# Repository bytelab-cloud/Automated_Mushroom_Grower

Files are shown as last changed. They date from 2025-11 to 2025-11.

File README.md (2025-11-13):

# Automated Mushroom Grower

Below is a list of components that are required for the project along with advice for assembling everything.

Youtube Video - https://youtu.be/puENLGAer3o

<h2>Components</h2>

<h3>Main</h3>

 - Switches - https://amzn.to/43ZM5kb

 - 2.1mm x 5.5mm Barrel Plug (Power) - https://amzn.to/488htiZ

 - Buck Converter 3.0-40V to 1.5-35V - https://amzn.to/49MK26M

 - Humidifier Module - https://amzn.to/47Rz90S

 - 24V Relay Module - https://amzn.to/4paiQUi

 - Arduino Uno - https://amzn.to/47DPRCc

 - Prototype PCB Board - https://amzn.to/3JXiYaw

 - 1.8" SPI LCD Display Module - https://amzn.to/4nQIpbJ

 - 1 Inch Diameter tube - https://amzn.to/4hRGUIU

 - 12v LED Strip - https://amzn.to/443jgU0

 - 12v Power Supply - https://amzn.to/4paiY6e

 - 60mm Fan - https://amzn.to/3JTiFO1

 - SHT 31 sensor - https://amzn.to/48c7MQA

   - I havent tested it but the code should also work with a cheaper SHT 30 sensor you just sacrifice some accuracy in readings

 - Resistors

 - Transistors

 - 100uf Capacitors

 - Wire / Jumper Wires

<h3>Optional</h3>

 - Pin Headers (For easier connection of jumpoer wires to pcb board)

 - Heat Set Inserts (I did not use them but it could make it easier)

 - Heat Shrink

<h2>Assembly</h2>

<h3>3D Printed Parts</h3>

Almost all of the 3D printed parts can just be screwed together except for the top part of the humidifier and the top of the case for the electronics. The case is designed this way so there isnt a need for a lot of supports when printing the case.

 - For the case for the electronics the top can welded together using acetone or glue the rest of assembly for the case just requires screws and is simple and straight foward to assemble.

 - The humidifier is made up of 3 different parts that require some form of welding or gluing.

     - For connecting the top plate of the humidifier to the bottom exhaust port you can use acetone to weld the parts together and use hot glue to create a seal around the edges.
  
     - For connecting the bottom exhaust to the top exhaust you can do the same acetone welding process to connect the 2 parts but to make sure it is sealed it is preferred to use silicone but hot glue works too.

 <h3>Electronics</h3>

 Most of the electronics are stright foward except for the screen which I have forund to work better when the LED power pin is connected the arduino rather then drawing 5v from the pcb.

  - <h3>Transistors (Humidifier Module and LED Strip)</h3>
  
    - 2 transistors are used in the machine 1 controls the humidifier module which is connected to pin 6 on the arduino along with the LED strip which gets connected to pin 3 on the arduino.
   
    - The humidifier module requires a simple modification for proper fuction you simply need to remove the push button on the module board so that when the board receives power it turns on automatically.

 - <h3>Relay (Fan)</h3>

    - The relay connects to the fan and requires 12v and is connected to pin 7 on the arduino

- <h3>Buck Converter</h3>

  - Depending on your power supply you with either need 1 or 2 buck converters if your using a 12v power supply you need to split it into 2 channels 1 that will directly connect to the pcb to powwer the 12v fan and LED strip and 1 channel that is stepped down to 5v in the buck converter that then connects to the pcb to power the rest of the electronics. If you are using a higher voltage power supply youll need 2 buck converters 1 that steps down to 12v and one that steps down to 5v both are connected the same way after passing through the buck converter.

- <h3>Switch</h3>

  - the switch gets connecteed to pin 12 on the arduino and ground.

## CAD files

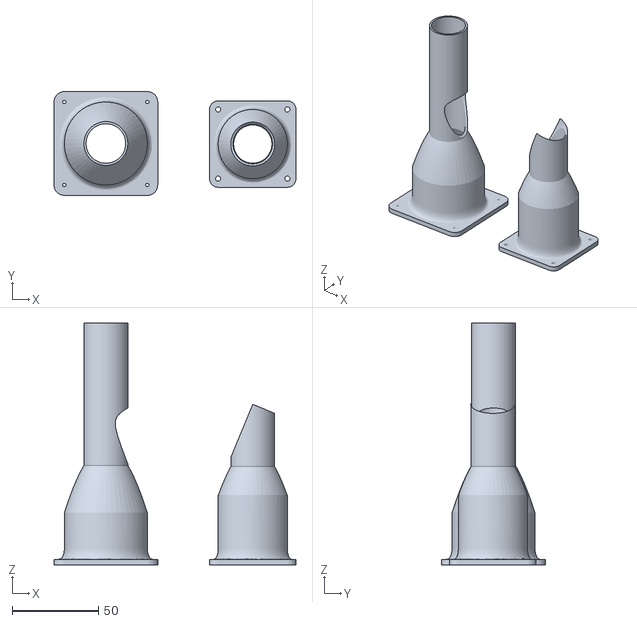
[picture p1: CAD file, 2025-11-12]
humidifier_exhaust.stl
139.9 x 60.0 x 139.7

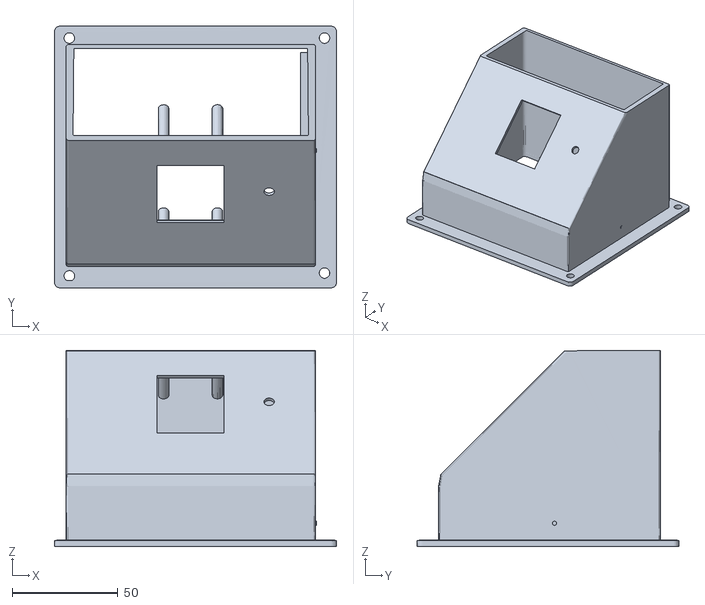
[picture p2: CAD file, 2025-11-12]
case.stl
133.3 x 123.8 x 92.7

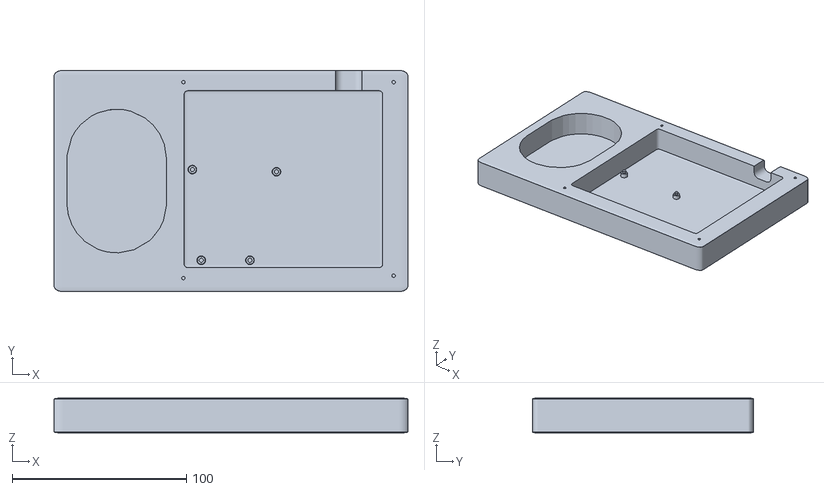
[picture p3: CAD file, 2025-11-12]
base_plate.stl
203.2 x 127.0 x 20.0

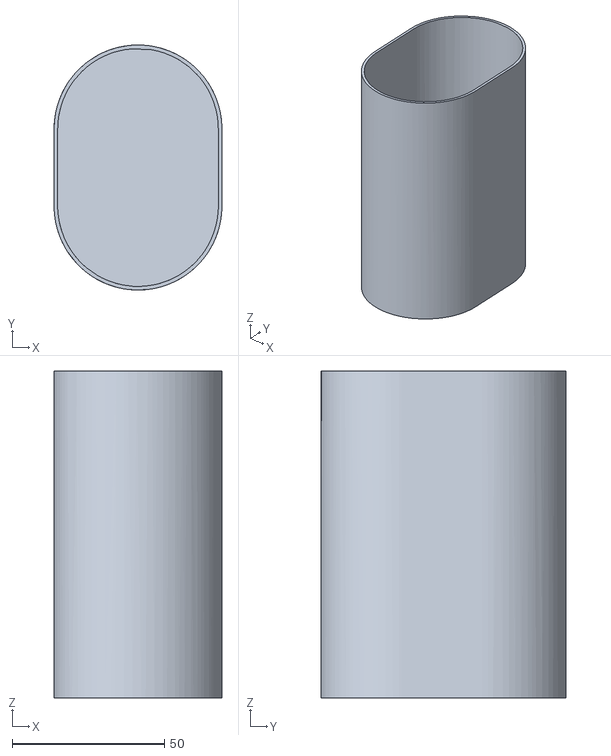
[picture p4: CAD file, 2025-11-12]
humidifier.stl
55.1 x 80.4 x 107.3

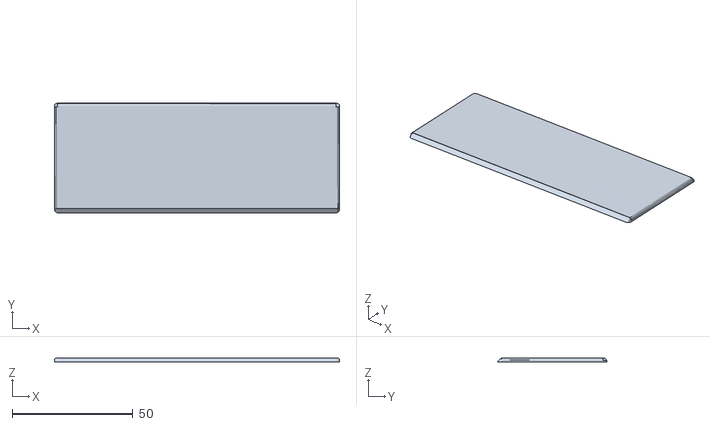
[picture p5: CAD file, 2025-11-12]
case_top.stl
118.0 x 45.4 x 1.80

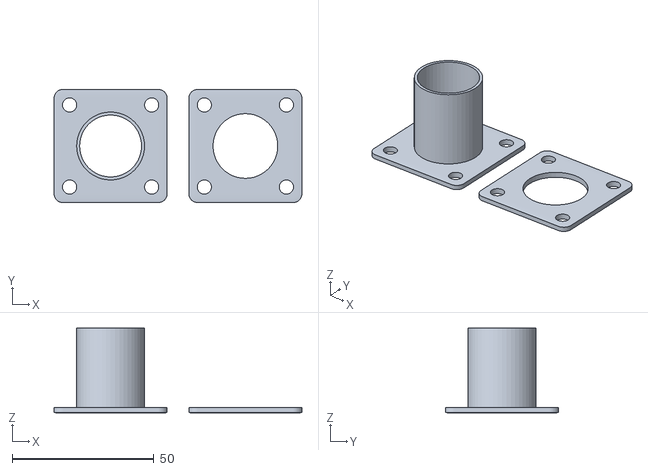
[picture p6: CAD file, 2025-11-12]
duct_flange.stl
87.6 x 40.0 x 30.0

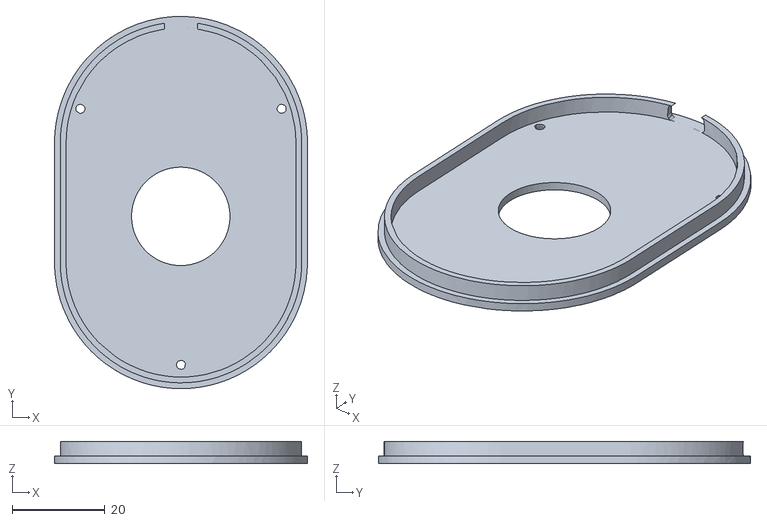
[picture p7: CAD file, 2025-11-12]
humidifier_lid.stl
54.7 x 80.5 x 4.80

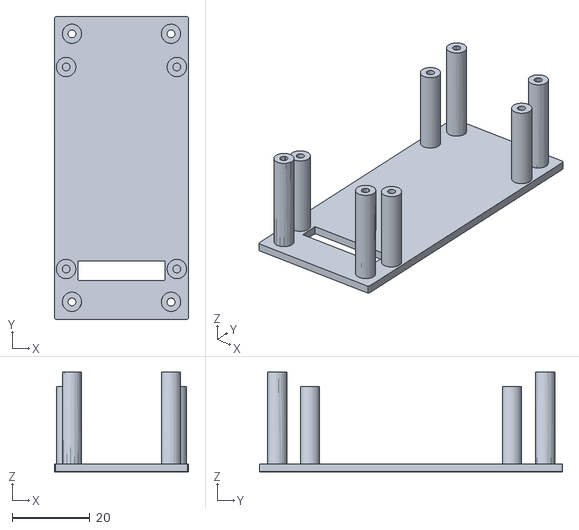
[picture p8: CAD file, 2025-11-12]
display_case.stl
34.5 x 78.0 x 25.6

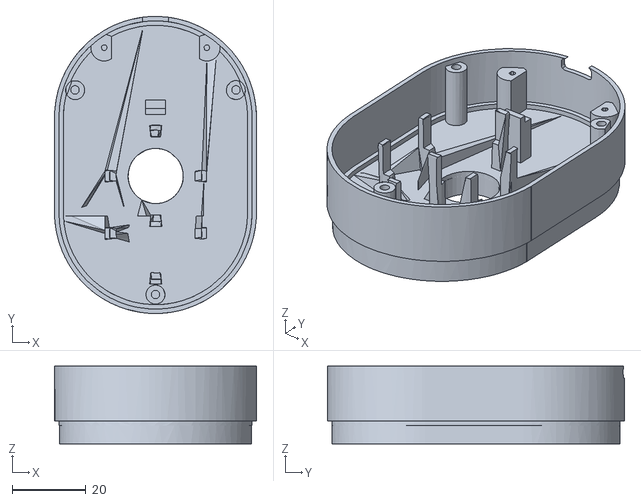
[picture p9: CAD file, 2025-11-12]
humidifier_top.stl
54.7 x 80.4 x 21.1

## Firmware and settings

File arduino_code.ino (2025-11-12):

#include <Adafruit_GFX.h>
#include <Adafruit_ST7735.h>
#include <Adafruit_SHT31.h>
#include <Wire.h>
#include <SPI.h>

// -------------------- Pin Definitions --------------------
#define TFT_CS   10
#define TFT_RST  8
#define TFT_DC   9

#define RELAY2   7
#define TRANSISTOR_PIN 6   // humidity control
#define LED_STRIP_PIN 3    // Transistor for LED strip
#define TOGGLE_SWITCH 12   // Switch input pin

// -------------------- Objects --------------------
Adafruit_ST7735 tft = Adafruit_ST7735(TFT_CS, TFT_DC, TFT_RST);
Adafruit_SHT31 sht31 = Adafruit_SHT31();

// -------------------- Timing Variables --------------------
unsigned long lastLEDToggle = 0;
bool ledState = false;
bool lastSwitchState = HIGH; 

// -------------------- Setup --------------------
void setup() {
  Serial.begin(9600);
  while (!Serial);
  Serial.println("Booting...");

  // Initialize TFT display 
  tft.initR(INITR_BLACKTAB);
  tft.setRotation(0); // Portrait
  tft.fillScreen(ST77XX_BLACK);
  tft.setTextColor(ST77XX_WHITE);
  tft.setTextSize(1);
  tft.setCursor(10, 5);
  tft.println("Environment Monitor");

  pinMode(RELAY2, OUTPUT);
  pinMode(TRANSISTOR_PIN, OUTPUT);
  pinMode(LED_STRIP_PIN, OUTPUT);
  pinMode(TOGGLE_SWITCH, INPUT_PULLUP); 

  // Default outputs 
  digitalWrite(RELAY2, HIGH);
  digitalWrite(TRANSISTOR_PIN, HIGH);
  digitalWrite(LED_STRIP_PIN, LOW); // Start LED off

  // Initialize SHT31
  if (!sht31.begin(0x44)) {
    Serial.println("Couldn't find SHT31 sensor!");
    tft.setTextColor(ST77XX_RED);
    tft.setCursor(10, 20);
    tft.println("SHT31 not found!");
  } else {
    Serial.println("SHT31 connected.");
    tft.setCursor(10, 20);
    tft.setTextColor(ST77XX_GREEN);
    tft.println("SHT31 OK");
  }

  delay(2000);
}

// -------------------- Loop --------------------
void loop() {
  float h = sht31.readHumidity();
  float t = sht31.readTemperature() * 9 / 5 + 32; // Convert °C to °F

  // --- Read Toggle Switch ---
  bool switchState = digitalRead(TOGGLE_SWITCH) == LOW;

  // --- Detect switch change ---
  if (switchState && !lastSwitchState) {
    ledState = true;
    digitalWrite(LED_STRIP_PIN, HIGH);
    lastLEDToggle = millis();
  }

  // --- LED Strip Logic ---
  if (switchState) {
    unsigned long currentMillis = millis();
    if (currentMillis - lastLEDToggle >= 43200000) { // 12 hours
      ledState = !ledState; // Toggle LED state
      digitalWrite(LED_STRIP_PIN, ledState ? HIGH : LOW);
      lastLEDToggle = currentMillis;
    }
  } else {
    // Switch is OFF → ensure LED is OFF
    ledState = false;
    digitalWrite(LED_STRIP_PIN, LOW);
  }

  // Remember the last switch state
  lastSwitchState = switchState;

  // --- Error Handling ---
  if (isnan(h) || isnan(t)) {
    Serial.println("Failed to read from SHT31 sensor!");

    tft.fillScreen(ST77XX_BLACK);
    tft.setCursor(10, 60);
    tft.setTextColor(ST77XX_RED);
    tft.setTextSize(2);
    tft.println("Sensor Error");

    delay(2000);
    return;
  }

  // --- Debug Output ---
  Serial.print("Humidity: ");
  Serial.print(h);
  Serial.print(" %  ");
  Serial.print("Temp: ");
  Serial.print(t);
  Serial.print(" *F  |  Switch: ");
  Serial.print(switchState ? "ON" : "OFF");
  Serial.print("  |  LED: ");
  Serial.println(ledState ? "ON" : "OFF");

  // --- Relay + Transistor Control ---
  if (h < 85) {
    digitalWrite(RELAY2, LOW); // ON when humidity < 85%
    digitalWrite(TRANSISTOR_PIN, HIGH); // ON when humidity < 85%
  } else {
    digitalWrite(RELAY2, HIGH); // OFF when humidity >= 85%
    digitalWrite(TRANSISTOR_PIN, LOW); // OFF when humidity >= 85%
  }

  // --- Update TFT Display ---
  tft.fillRect(0, 20, 128, 140, ST77XX_BLACK);

  // Humidity
  tft.setCursor(16, 20);
  tft.setTextColor(ST77XX_CYAN);
  tft.setTextSize(2);
  tft.print("Humidity");

  tft.setCursor(20, 40);
  tft.setTextColor(ST77XX_MAGENTA);
  tft.setTextSize(3);
  tft.print(h, 1);
  tft.print("%");

  // Temperature
  tft.setCursor(40, 65);
  tft.setTextColor(ST77XX_CYAN);
  tft.setTextSize(2);
  tft.print("Temp");

  tft.setCursor(10, 85);
  tft.setTextColor(ST77XX_MAGENTA);
  tft.setTextSize(3);
  tft.print(t, 1);
  tft.print(" F");

  // Switch + LED status
  tft.setCursor(35, 115);
  tft.setTextSize(1);
  tft.setTextColor(switchState ? ST77XX_GREEN : ST77XX_YELLOW);
  tft.print("Switch: ");
  tft.println(switchState ? "ON" : "OFF");

  tft.setCursor(42, 125);
  tft.setTextColor(ledState ? ST77XX_GREEN : ST77XX_YELLOW);
  tft.print("LED: ");
  tft.println(ledState ? "ON" : "OFF");

  delay(500); 
